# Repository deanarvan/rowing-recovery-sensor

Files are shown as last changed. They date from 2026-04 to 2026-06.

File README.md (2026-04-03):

# Rowing Recovery Sensor

A bilateral force-sensing platform for physical therapy rehabilitation monitoring. Built for tracking lower-extremity recovery metrics — limb symmetry index (LSI), bilateral weight distribution, and force production — during exercises like bilateral stance, heel raises, and squats.

## System Architecture

```
ESP32-S3  →  2× ADS1115 (16-bit ADC)  →  6× FSR-402 sensors  →  BLE  →  Web App
              I2C (GPIO8/9)              (3 per foot: heel,       50 Hz    React/Vite
                                          ball, toe)                       localhost:5174
```

## Repository Structure

```
firmware/           ESP32 Arduino firmware
  rowing_sensor/    Main 6-axis force sensor firmware
  balance_board/    4-load-cell balance board variant
  diagnostics/      I2C scanner and pin finder tools

hardware/           PCB design and build documentation
  kicad/            KiCad schematic, layout, BOM, netlist
  documentation/    Assembly guides, pin reference, design notes

web/                React/Vite web application
  src/components/   UI components (force curves, balance viz, diagnostics)
  src/hooks/        BLE communication, data processing, stroke analysis
  src/utils/        Biomechanics algorithms, session export, calibration

tools/              Python analysis and data logging
  achilles_recovery_analysis.py   Longitudinal PT recovery analysis
  compare_subjects.py             Bilateral comparison report generator
  balance_logger.py               Serial data logger

docs/research/      Biomechanics and rehabilitation reference literature
```

## Quick Start

### Firmware
1. Open `firmware/rowing_sensor/rowing_firmware.ino` in Arduino IDE
2. Select board: ESP32-S3 Dev Module
3. Install library: Adafruit ADS1X15
4. Flash to ESP32-S3

### Web App
```bash
cd web
npm install
npm run dev
# Opens at http://localhost:5174
```

Connect to the sensor via Web Bluetooth (device name: `Rowing_Sensors`).

### Hardware
See `hardware/documentation/START_HERE.txt` for build instructions.

## Key Metrics

| Metric | Description | Clinical Threshold |
|---|---|---|
| LSI | Limb Symmetry Index (injured/uninvolved × 100) | >90% return to sport |
| BSI | Balance Symmetry Index (bilateral weight asymmetry) | <10% general activity |
| Peak Force | BW-normalized peak plantarflexion force | >1.5× BW running readiness |

## Hardware Versions

- **Breadboard prototype**: ESP32-S3 + breadboard + 6× FSR-402 + 2× ADS1115
- **PCB v1**: Custom PCB with same sensor array, improved signal integrity
- **Balance Board**: 4× load cell variant for standing balance assessment

## License

Private — not for redistribution.

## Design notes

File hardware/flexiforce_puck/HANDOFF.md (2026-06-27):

# FlexiForce A301 load-concentrator puck — HANDOFF

**CURRENT:** `make_puck_v3.py` → `flexiforce_puck_4up_v3.stl` (low-profile 4-up, PRINT THIS). Prior: v2 (8 mm×3 mm 4-up), v1 (single).
**Purpose:** rigid disc that routes the balance-board/top-plate load THROUGH it onto the
A301's 9.53 mm active sensing area. Without it the load spreads across the flat sensor and the
A301 under-reads (the ~600-1200 raw-count standing reads in the bring-up). Pure **axial
compression** along the puck axis (+Z); no bending/tension/shear in the intended rig.

## Versions
### v1 (CURRENT) — CadQuery B-rep, chamfered disc
- Params: `PUCK_DIA=8.0`, `PUCK_H=3.0`, `CHAMFER=0.5` (mm). Sensing-area ref `9.53`.
- Build: `circle → extrude → chamfer("%CIRCLE")`. Exports STL + STEP.
- Result (verify all PASS): watertight, single body, euler=2 (plain solid), bbox 8×8×3 mm,
  axisymmetric (COM x,y≈0), top/bottom symmetric (COM z=1.5).
- Numbers: flat contact dia **7.0 mm**; coverage of 9.53 mm area = **84% OD / 73% flat**;
  volume 0.145 cm³; mass **PLA 0.179 g / PETG 0.184 g / PAHT-CF 0.174 g**; 4 pucks ≈ 0.74 g.

### v2 (CURRENT for a set) — 4-up print plate
- `make_puck_v2.py`: same puck, 2×2 grid, `GAP=5` mm → 13 mm pitch, **21×21 mm plate**, 4 SEPARATE bodies.
- Verify all PASS: watertight, **body count 4**, euler **8** (4 disjoint solids), per-body vol = v1 (0.1447 cm³),
  layout symmetric (COM x,y≈0).
- Set mass: **PLA 0.72 g / PETG 0.74 g / PAHT-CF 0.69 g**. A slicer brim across the 5 mm gap holds the four
  during the print, then peels off — no connecting tabs, so nothing to clean off the functional faces.

### v3 (CURRENT) — low-profile, sensor-matched diameter
- `make_puck_v3.py`: **9.5 mm OD × 1.0 mm tall**, 4-up 2×2 @ 14.5 mm pitch → **24×24 mm plate**, CHAMFER 0.3.
- Diameter raised from 8→9.5 to **= the 9.53 mm active area** (full coverage, no overhang). Do NOT exceed 9.53:
  a wider puck overhangs onto the board and load bypasses the sensor (~⅓ reaches the active area at 16 mm) → under-reads.
- Height cut 3→1 mm (low profile, aspect 9.5:1). Symmetric top/bottom (no wrong way up).
- Verify all PASS incl. `OD covers active area` (PUCK_DIA ≤ 9.53) and `4 bodies identical`. Set mass **PETG 0.35 g**.
- **Open design note:** if the user stands *directly* on the pucks (no rigid top-plate), small hard discs are
  uncomfortable and the contact point wanders → poor CoP. Proper construction = rigid top-plate over the 4
  pucks; then the plate handles comfort and the puck stays at the optimal 9.5 mm. A top-plate STL is not yet built.

## HARD INVARIANTS
- `PUCK_DIA < SENSOR_AREA_DIA (9.53)` — puck MUST stay inside the active circle (off-area load = error).
- `PUCK_H` MUST exceed everything else between the sensor and the top plate, or load bypasses the puck.
- euler_number == 2 (plain solid, no holes). Axisymmetric; COM on the z-axis.

## GOTCHAS
- `.edges("%CIRCLE")` chamfers only the two rims, skipping the OCC cylinder seam edge (a LINE).
- Tiny footprint (7 mm flat) → use a **brim** so it doesn't pop off the bed.
- **PLA creeps under sustained bodyweight compression** — use PETG or PAHT-CF for real pucks; PLA only for a fit-check.
- Print **100% infill** (solid) — a load concentrator must not crush; sparse infill would collapse.

## PRINT ORIENTATION (recommended)
**Flat — disc on the bed, axis vertical (layers horizontal, perpendicular to the load).**
- Axial compression loads the layer stack in compression (layers pushed together) = the strong
  direction for FDM; interlayer adhesion (the weak axis) is irrelevant here.
- Both functional faces (top + bottom flats) print flat; no supports; best diameter/height accuracy; fast (3 mm).
- Put the **sensor-contact face UP** and enable **iron top surface** for the flattest contact (marginal — the
  part is nearly symmetric, so either face down is fine; the 0.5 mm chamfer mitigates elephant-foot on the bed face).
- **Flips the call only if** the top plate imparts real SHEAR to the pucks (sliding plate) — then on-edge layers
  would delaminate; stay flat but use PAHT-CF and/or bond the puck down.
- Kit: X2D, PAHT-CF (dried) or PETG, brim, 100% infill, no supports. 0.4 mm nozzle gives crisper chamfers than the
  PAHT-CF 0.6 mm nozzle on a part this small, but 0.6 mm works.

## START BY
Confirm `PUCK_H` matches the real sensor→top-plate gap (the one dimension tied to the assembly), then
`python3 make_puck_v3.py`. Print `flexiforce_puck_4up_v3.stl` (current set of 4). Keep `PUCK_DIA ≤ 9.53`
(active-area rule). Changed a knob? Re-run the script — the verify guard fails loud if the geometry breaks.

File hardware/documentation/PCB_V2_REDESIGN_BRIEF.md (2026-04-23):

# Rowing/Balance Board Rehabilitation Sensor — PCB Design Brief

**Project:** Rowing/Balance Board Rehabilitation Sensor
**Board Size:** 50mm × 70mm, 2-layer
**Manufacturing:** JLCPCB / PCBWay compatible (PCBA assembly service preferred)
**Deliverables:** KiCad schematic (.kicad_sch), PCB layout (.kicad_pcb), Gerbers, BOM with LCSC part numbers, pick-and-place file

---

## Project Overview

This PCB is the central electronics module for a bilateral force-sensing platform used in physical therapy rehabilitation monitoring. It reads four thin-film force sensors (Tekscan FlexiForce A301-100), measures board orientation via a 9-DOF IMU, and streams the combined data to a web application over Bluetooth Low Energy at 50 Hz.

The same hardware supports two operating modes, selected by sensor placement:
- **Rowing mode** — FlexiForce sensors placed in shoe insoles (heel + toe of each foot). The web app detects stroke phases and analyzes force curves.
- **Balance board mode** — FlexiForce sensors placed on a balance platform at heel + toe positions for each foot. The web app computes center of pressure (CoP), sway velocity, ellipse area, and drives interactive balance training games.

Both modes use the same 4 sensor channels and the same BLE data format. The user physically swaps sensor sets by plugging different cables into the 4 front-panel headers.

### Key Design Requirements

| Requirement | Value |
|---|---|
| Force sensor channels | 4 (2 per foot: heel + toe) |
| Force measurement range (per sensor) | 0 to ~2,000 N |
| Sensor type | Tekscan FlexiForce A301-100 thin-film |
| Orientation sensing | 9-DOF IMU (pitch, roll, yaw) |
| Sample rate | 50 Hz per channel |
| Wireless protocol | Bluetooth Low Energy (BLE 5.0) |
| Power input | 5V USB-C |
| Regulated rail | 3.3V (1A capable LDO) |
| Programming | USB serial via CP2102N bridge |
| Board outline | 50mm × 70mm, 2-layer |

---

## System Block Diagram

```
┌─────────────┐
│  USB-C 5V   │
└──────┬──────┘
       │
       ├─ CP2102N USB-to-UART Bridge (U2)
       │  (TX → ESP32 GPIO1, RX ← ESP32 GPIO3)
       │
       ├─ AP2112K-3.3 LDO (U1) ── 3.3V rail
       │
       ├─ ESP32-WROOM-32 (U3)
       │  ├─ I2C SDA = GPIO21, SCL = GPIO22
       │  ├─ GPIO0 (BOOT button)
       │  ├─ EN (RESET button)
       │  └─ BLE antenna (keep-out zone required)
       │
       ├─ MCP6004 Quad Op-Amp (U4) — analog conditioning
       │  ├─ Ch A → FlexiForce: Left Heel  → ADS1115 A0
       │  ├─ Ch B → FlexiForce: Left Toe   → ADS1115 A1
       │  ├─ Ch C → FlexiForce: Right Heel → ADS1115 A2
       │  └─ Ch D → FlexiForce: Right Toe  → ADS1115 A3
       │
       ├─ ADS1115 16-bit I2C ADC @ 0x48 (U5)
       │  ├─ A0-A3 ← Op-amp outputs
       │  ├─ ADDR → GND (sets address 0x48)
       │  └─ Shares I2C bus with IMU
       │
       └─ BNO055 9-DOF IMU @ 0x28 (U6, on-board LGA-28 IC with 32.768 kHz crystal)
          ├─ Outputs: Euler angles, quaternion, linear acceleration
          ├─ ADR → GND (sets address 0x28)
          └─ Shares I2C bus with ADC
```

---

## Analog Front-End Design

### FlexiForce A301 Conditioning Circuit (per channel, ×4)

The FlexiForce A301 is a 2-terminal resistive force sensor. Its resistance decreases as applied force increases. An **inverting op-amp circuit** converts this variable resistance to a proportional output voltage with good linearity across the full force range.

The topology follows the **Tekscan FlexiForce Integration Guide, Figure 4** ("Inverting Amplifier" reference circuit). Per channel:

```
  ┌─────────── Rf (10 kΩ) ──────────┐
  │                                 │
  │        ┌───────────────┐        │
Vref ──────┤(–)             ├───────┴──────┬──── Vout → ADS1115 input (A0–A3)
           │   MCP6004      │              │
    ┌──────┤(+)  (1 of 4)   │              Cf (100 pF, optional)
    │      └───────────────┘               │
   Vref/2 reference                        GND
    │
  (mid-rail bias divider)

  FlexiForce sensor — wired between Vref (drive node) and the (–) input,
  replacing the standard input resistor Rin in the inverting configuration.
```

**Operating principle:** the FlexiForce sits in the position of the inverting-amplifier input resistor. As applied force increases, Rsensor decreases, input current into the summing junction rises, and Vout moves proportionally. The feedback resistor Rf sets the gain (force range). The (+) input is biased to mid-rail (Vref/2) to keep the single-supply op-amp output in the linear region.

Full schematic with exact polarity and biasing: see Tekscan Integration Guide (linked in the Reference Datasheets section). Standard values given below are calibrated for this application.

The op-amp output follows the relation **Vout = Vref × (Rf / Rsensor)**. As force increases, Rsensor decreases, and Vout increases linearly — from ~0V (no force) to ~3V (full range).

### Component Values (per channel)

| Component | Value | Tolerance | Package | Purpose |
|---|---|---|---|---|
| Rf (feedback resistor) | 10 kΩ | 1% | 0603 | Sets force range to ~0–2,000 N |
| Rd (drive resistor) | 10 kΩ | 1% | 0603 | Sets reference current |
| Cf (output filter cap) | 100 pF | 10% | 0603 | Optional low-pass filter |

**Force range tuning** — the Rf value selects the measurement range. 10 kΩ is recommended for this rehabilitation use case:

| Rf | Force Range | Use Case |
|---|---|---|
| 49.9 kΩ | 0 – 445 N | Light touch, seated exercises |
| **10 kΩ** (chosen) | **0 – 2,000 N** | **Standing, squats, heel raises** |
| 4.7 kΩ | 0 – 3,500 N | Heavy dynamic loading |
| 1 kΩ | 0 – 4,448 N | Impact / jump landing |

### Shared Vref Generation

A single voltage divider off the 3.3V rail generates the reference voltage used by all 4 op-amp channels.

```
3.3V ─── Rvd1 (47kΩ) ──┬── Vref (~0.58V) → to Rd on each channel
                         │
                    Rvd2 (10kΩ)
                         │
                        GND
                         │
                    Cvref (100nF to GND)
```

**Vref = 3.3V × 10kΩ / (47kΩ + 10kΩ) ≈ 0.58V**

This low reference voltage keeps the op-amp output within the ADS1115's 0–3.3V input range across the full force range.

### MCP6004 Quad Op-Amp (U4)

The MCP6004 is a quad rail-to-rail input/output op-amp in SOIC-14. A single chip handles all 4 sensor channels.

```
MCP6004 (SOIC-14)
┌──────────────────┐
│ 1  OUT_A    VDD 14│──── 3.3V
│ 2  IN-_A   OUT_D 13│──── → ADS1115 A3 (Right Toe)
│ 3  IN+_A   IN-_D 12│──── Rf_D + Rd_D
│ 4  VSS     IN+_D 11│──── GND (sensor reference)
│ 5  IN+_B   IN-_C 10│──── Rf_C + Rd_C
│ 6  IN-_B   IN+_C  9│──── GND (sensor reference)
│ 7  OUT_B   OUT_C   8│──── → ADS1115 A2 (Right Heel)
└──────────────────┘
```

Channel assignments:

| MCP6004 Channel | OUT / IN– / IN+ pins | Sensor | ADS1115 Input |
|---|---|---|---|
| A | 1 / 2 / 3 | Left Heel | A0 |
| B | 7 / 6 / 5 | Left Toe | A1 |
| C | 8 / 10 / 9 | Right Heel | A2 |
| D | 13 / 12 / 14 | Right Toe | A3 |

**Power:** VDD (pin 14) to 3.3V with 100nF + 10µF decoupling placed within 5mm of the pin. VSS (pin 4) to ground plane.

---

## Digital Section

### ADS1115 16-bit ADC (U5)

Single ADS1115 reads all 4 op-amp outputs over I2C.

| Pin | Name | Connection |
|---|---|---|
| 1 | VDD | 3.3V (with 100nF decoupling cap to GND) |
| 2 | A0 | MCP6004 Channel A output (Left Heel) |
| 3 | A1 | MCP6004 Channel B output (Left Toe) |
| 4 | A2 | MCP6004 Channel C output (Right Heel) |
| 5 | A3 | MCP6004 Channel D output (Right Toe) |
| 6 | GND | Ground plane |
| 7 | SDA | I2C SDA bus (GPIO21) |
| 8 | SCL | I2C SCL bus (GPIO22) |
| 9 | ADDR | GND (sets I2C address to 0x48) |
| 10 | ALERT | Leave unconnected |

### BNO055 9-DOF IMU (U6)

The BNO055 provides absolute orientation with onboard sensor fusion (Euler angles, quaternion, linear acceleration, gravity vector) — no host-side filtering required. The IC is placed **directly on the PCB** alongside its supporting crystal and decoupling components. JLCPCB's PCBA service handles the LGA-28 placement; no post-assembly work is required.

#### BNO055 IC Pinout (LGA-28)

| Pin | Name | Connection |
|---|---|---|
| 1 | VDDIO | 3.3V (with 100nF decoupling cap to GND) |
| 3 | GND | Ground plane |
| 4 | XIN32 | Crystal pin 1 (with 22pF load cap to GND) |
| 5 | XOUT32 | Crystal pin 2 (with 22pF load cap to GND) |
| 6 | BL_IND | 10 kΩ pull-up to 3.3V |
| 8 | PS1 | GND (standard I²C mode) |
| 9 | PS0 | GND (standard I²C mode) |
| 17 | COM3 (ADR) | GND (sets I²C address to 0x28) |
| 18 | COM2 (INT) | ESP32 GPIO4 (optional motion interrupt; leave floating if unused) |
| 19 | COM1 (SCL) | I²C SCL bus (GPIO22) |
| 20 | COM0 (SDA) | I²C SDA bus (GPIO21) |
| 23 | nRESET | Pull up to 3.3V via 10 kΩ; optional tie to ESP32 GPIO5 for hardware reset |
| 28 | VDD | 3.3V (with 100nF decoupling cap to GND) |

(All other pins: leave unconnected or tied to GND per datasheet recommendations.)

#### Supporting Components

| Ref | Value | Purpose |
|---|---|---|
| Y1 | 32.768 kHz quartz crystal, 12.5 pF load | External timing reference — required for accurate sensor fusion |
| Cxtal1, Cxtal2 | 22 pF NP0 | Crystal load capacitors (tie to GND, placed within 3mm of crystal) |
| Cbno_io | 100 nF | VDDIO decoupling (placed within 2mm of pin 1) |
| Cbno_d | 100 nF | VDD decoupling (placed within 2mm of pin 28) |
| Rbl | 10 kΩ | BL_IND pull-up to 3.3V |
| Rrst | 10 kΩ | nRESET pull-up to 3.3V |

Crystal routing: keep traces short and symmetric, surround with ground pour, do not route high-speed signals underneath.

### I2C Bus

Both devices share one I2C bus driven by the ESP32 on GPIO21 (SDA) and GPIO22 (SCL).

| Device | Address | Package |
|---|---|---|
| ADS1115 | 0x48 | MSOP-10 on-board |
| BNO055 | 0x28 | LGA-28 on-board |

Bus pull-ups: 4.7 kΩ to 3.3V on both SDA and SCL. 400 kHz fast mode.

### IMU Axis Alignment

Orient the BNO055 IC on the PCB so that its internal axes align with the board's physical frame of reference:

- **IMU X+** → board length direction (anterior, toward the toe-end of the sensor layout)
- **IMU Y+** → board width direction (medial-lateral)
- **IMU Z+** → up (perpendicular to PCB surface)

With this alignment, pitch rotates around Y, roll rotates around X, yaw rotates around Z. Document the chosen orientation on the silkscreen with a small arrow so the operator can verify placement.

### ESP32-WROOM-32 (U3)

Standard ESP32-WROOM-32 module handles all logic and BLE wireless.

| Pin | Name | Connection |
|---|---|---|
| 1 | GND | Ground plane |
| 2 | VCC | 3.3V rail |
| 3 | RXD (GPIO3) | UART RX from CP2102N |
| 4 | EN | RESET button + 10 kΩ pull-up to 3.3V |
| 27 | GPIO0 | BOOT button + 10 kΩ pull-up to 3.3V |
| 21 | GPIO21 | I2C SDA (4.7 kΩ pull-up) |
| 22 | GPIO22 | I2C SCL (4.7 kΩ pull-up) |

**Antenna keep-out:** no copper (traces or ground plane) within 10mm of the ESP32 antenna end. The antenna should overhang the board edge or sit in a dedicated clear zone.

### CP2102N USB-to-UART Bridge (U2)

Standard USB programming interface.

| Pin | Name | Connection |
|---|---|---|
| 1 | VCC | 3.3V (with 100nF decoupling) |
| 3 | D+ | USB connector D+ (via 22Ω series resistor) |
| 4 | D- | USB connector D- (via 22Ω series resistor) |
| 5 | TXD | ESP32 GPIO1 (via 1 kΩ series resistor) |
| 6 | RXD | ESP32 GPIO3 (via 1 kΩ series resistor) |
| 10 | REGIN | 5V rail (with 100nF decoupling) |

### Power Supply

| Net | Voltage | Source | Notes |
|---|---|---|---|
| 5V_USB | 5.0V | USB-C connector | Max 500 mA per USB spec |
| 3V3 | 3.3V | AP2112K-3.3 LDO | 600 mA capacity; 55 µA quiescent; typical draw <200 mA |
| GND | 0V | Continuous ground plane | |

Decoupling: 100nF + 10µF on LDO input and output. 100nF per IC VDD pin placed within 5mm.

---

## Sensor Connectors

**4× 2-pin 2.54mm female through-hole headers (J2–J5)**

The FlexiForce A301 terminates in 2 male square pins at 0.1" pitch. These plug directly into standard 2-pin female headers on the PCB — no adapter cables, no soldering to the sensor, easy swap for replacement.

| Connector | Sensor | Op-Amp Channel | ADS1115 Input |
|---|---|---|---|
| J2 | Left Heel FlexiForce | MCP6004 Ch A | A0 |
| J3 | Left Toe FlexiForce | MCP6004 Ch B | A1 |
| J4 | Right Heel FlexiForce | MCP6004 Ch C | A2 |
| J5 | Right Toe FlexiForce | MCP6004 Ch D | A3 |

**Each connector:**
- Pin 1: Sensor signal → 100 Ω series resistor → TVS clamp → MCP6004 IN+ (non-inverting input)
- Pin 2: GND

**Part:** 2-pin 2.54mm female header, through-hole (LCSC C35165 or equivalent). Place J2–J5 along one board edge for clean cable routing.

### ESD Protection (per sensor input)

Since FlexiForce sensors will be plugged and unplugged repeatedly during clinical use, each sensor input gets basic ESD/transient protection between the connector and the op-amp input:

| Component | Value | Purpose | Placement |
|---|---|---|---|
| Resd (×4) | 100 Ω | Series current-limit resistor on signal pin | Between J2–J5 pin 1 and TVS clamp |
| D_esd (×4) | PESD3V3L1BA | Unidirectional TVS diode, 3.3V working voltage, SOD-523 package | Between signal (after Resd) and GND, cathode to signal |

This adds negligible noise (100 Ω against the op-amp's MΩ-range input impedance is invisible) but clamps any static discharge or cable swap transient before it reaches the op-amp.

---

## Bill of Materials

All components mount directly on the PCB. The only off-board items are the FlexiForce sensors themselves, which plug into the four front-edge headers.

| Designator | Value / Part | Description | Package | LCSC | Qty |
|---|---|---|---|---|---|
| U1 | AP2112K-3.3TRG1 | 3.3V LDO regulator, 55 µA Iq, low dropout | SOT-25 | C51118 | 1 |
| U2 | CP2102N | USB-to-UART bridge | QFN-28 | C7520 | 1 |
| U3 | ESP32-WROOM-32 | BLE/WiFi MCU module | 38-pin module | C529143 | 1 |
| U4 | MCP6004-I/ST | Quad rail-to-rail op-amp | SOIC-14 | C7378 | 1 |
| U5 | ADS1115 | 16-bit I²C ADC | MSOP-10 | C21992 | 1 |
| U6 | BNO055 | 9-DOF absolute orientation sensor with onboard fusion | LGA-28 (5.2×3.8mm) | C40521 | 1 |
| Y1 | 32.768 kHz crystal, 12.5 pF load | BNO055 external timing crystal | SMD 3.2×1.5mm | C32346 | 1 |
| Cxtal1 | 22 pF NP0 | Crystal load cap | 0402 | C1554 | 1 |
| Cxtal2 | 22 pF NP0 | Crystal load cap | 0402 | C1554 | 1 |
| Cbno_io | 100 nF | BNO055 VDDIO decoupling | 0402 | C1525 | 1 |
| Cbno_d | 100 nF | BNO055 VDD decoupling | 0402 | C1525 | 1 |
| Rbl | 10 kΩ | BNO055 BL_IND pull-up | 0402 | C25744 | 1 |
| Rrst | 10 kΩ | BNO055 nRESET pull-up | 0402 | C25744 | 1 |
| Rf1–Rf4 | 10 kΩ 1% | Op-amp feedback resistors | 0603 | C25804 | 4 |
| Rd1–Rd4 | 10 kΩ 1% | Op-amp drive resistors | 0603 | C25804 | 4 |
| Rvd1 | 47 kΩ 1% | Vref divider (top) | 0603 | C25819 | 1 |
| Rvd2 | 10 kΩ 1% | Vref divider (bottom) | 0603 | C25804 | 1 |
| R10 | 4.7 kΩ | I²C SDA pull-up | 0603 | C14631 | 1 |
| R11 | 4.7 kΩ | I²C SCL pull-up | 0603 | C14631 | 1 |
| R12 | 10 kΩ | GPIO0 (BOOT) pull-up | 0603 | C14663 | 1 |
| R13 | 10 kΩ | EN (RESET) pull-up | 0603 | C14663 | 1 |
| R14 | 22 Ω | USB D+ series resistor | 0603 | C25119 | 1 |
| R15 | 22 Ω | USB D- series resistor | 0603 | C25119 | 1 |
| R_LED | 1 kΩ | Power LED current limit | 0603 | C14663 | 1 |
| R_UART1 | 1 kΩ | CP2102 TX series | 0603 | C14663 | 1 |
| R_UART2 | 1 kΩ | CP2102 RX series | 0603 | C14663 | 1 |
| Cvref | 100 nF | Vref bypass cap | 0603 | C14663 | 1 |
| Cpa | 100 nF | MCP6004 VDD decoupling | 0603 | C14663 | 1 |
| Cpb | 10 µF | MCP6004 VDD bulk cap | 1206 | C13585 | 1 |
| Ca5 | 100 nF | ADS1115 VDD decoupling | 0603 | C14663 | 1 |
| C1 | 100 nF | CP2102N VCC decoupling | 0603 | C14663 | 1 |
| C2 | 10 µF | Input bulk cap (5V) | 1206 | C13585 | 1 |
| C3 | 100 nF | LDO output decoupling | 0603 | C14663 | 1 |
| C4 | 10 µF | LDO output bulk cap | 1206 | C13585 | 1 |
| C5 | 100 nF | ESP32 VCC decoupling | 0603 | C14663 | 1 |
| C10 | 100 nF | BOOT debounce (optional) | 0603 | C14663 | 1 |
| C11 | 100 nF | RESET debounce (optional) | 0603 | C14663 | 1 |
| LED1 | Red LED | Power indicator | 0603 | C2286 | 1 |
| SW1 | 6×6mm tactile button | BOOT | SMD 6×6mm | C318884 | 1 |
| SW2 | 6×6mm tactile button | RESET | SMD 6×6mm | C318884 | 1 |
| J1 | USB-C receptacle, 24-pin | USB connector (mid-mount) | USB-C SMD | C165948 | 1 |
| J2–J5 | 2-pin female header, 2.54mm | Sensor connectors | TH 2.54mm | C35165 | 4 |
| Resd1–Resd4 | 100 Ω | Sensor input series resistor (ESD current limit) | 0402 | C25092 | 4 |
| Desd1–Desd4 | PESD3V3L1BA | Unidirectional TVS diode, 3.3V clamping | SOD-523 | C129319 | 4 |

Estimated per-board cost: ~$15 in components plus ~$2–5 PCB fabrication (JLCPCB 5-piece minimum).

### Off-Board Parts (Not on PCB)

| Part | Source | Purpose |
|---|---|---|
| Tekscan FlexiForce A301-100 (×4 or ×6 with spares) | DigiKey / Tekscan | Force sensors; plug into J2–J5 |

The IMU is integrated directly on the PCB — no separate module to purchase.

---

## PCB Layout Guidelines

### Analog Signal Routing (Critical)

1. **Keep MCP6004 output traces short** — route directly to ADS1115 inputs with minimal trace length (<10mm ideal).
2. **Star ground** — connect MCP6004 VSS, ADS1115 GND, and the Vref divider bottom to a single node on the ground plane near the analog section.
3. **Separate analog and digital zones** — ESP32 and CP2102N on one side of the board, MCP6004/ADS1115/BNO055 on the other. Join the two zones at a single point under the LDO.
4. **Vref trace** — route the Vref net from the divider to all 4 Rd resistors on the top layer, keep away from digital switching traces.
5. **Sensor connector placement** — J2–J5 along one edge for easy cable routing.

### Suggested Component Placement

```
50mm × 70mm Board (Top View)
┌────────────────────────────────────────┐
│  [USB-C]  [CP2102N]  [LED] [SW1][SW2] │  ← Digital section (top edge)
│                                        │
│         [ESP32-WROOM-32]               │  ← Center; keep antenna clear
│         (large module)                 │
│                                        │
│  [MCP6004]  [ADS1115]    [BNO055]     │  ← Analog + IMU section
│  [Rf1-4]    [Rd1-4]      [Y1 xtal]    │     IMU IC directly on board
│  [Rvd1/2]   [Cvref]                   │
│                                        │
│  [J2]  [J3]  [J4]  [J5]              │  ← Sensor connectors (bottom edge)
└────────────────────────────────────────┘
```

### Trace / Via Specifications

- Signal traces: 0.25mm minimum width
- Power traces: 0.5mm minimum width
- Via diameter: 0.3mm minimum drill, 0.6mm pad
- Ground plane: continuous on bottom layer
- 2-layer, 1oz copper

### ESP32 Antenna Keep-Out

No copper (traces or ground plane) within 10mm of the ESP32 antenna end. The module should be oriented so the antenna overhangs the board edge or has a dedicated clear zone.

### IMU Placement

Place the BNO055 IC (U6) and its 32.768 kHz crystal (Y1) together in a small quiet zone, away from the ESP32 module and high-speed digital traces. Surround the crystal with a local ground pour. Add a silkscreen arrow next to U6 indicating the chosen X-axis direction so firmware and the web app can interpret axes correctly. The 22 pF load caps (Cxtal1, Cxtal2) must be within 3 mm of the crystal pins.

---

## Calibration Procedure (Post-Assembly)

Run once per assembled board to establish per-channel force calibration:

1. Power the board with no load on any sensor — record the zero-offset ADC reading per channel.
2. Place a known weight (e.g., 20 kg plate) centered on each FlexiForce sensor — record the loaded ADC reading.
3. Compute per-channel scale factor: `scale = known_force_N / (loaded_reading − zero_reading)`.
4. Store scale factors in ESP32 non-volatile storage (NVS) or hardcode in firmware.

**Expected with Rf = 10 kΩ:** approximately 16 ADC counts per Newton, so the full 0–2000 N range maps to 0–32,000 counts (well within the ADS1115's 16-bit resolution).

---

## Testing Checklist

### Power-On
- [ ] LED1 illuminates
- [ ] 3.3V rail measures 3.28–3.35 V
- [ ] Current draw <100 mA with no BLE connection

### Vref Verification
- [ ] Measure Vref node: 0.55–0.60 V

### Op-Amp Verification (sensors disconnected)
- [ ] MCP6004 pin 14 (VDD): 3.3 V
- [ ] MCP6004 pin 4 (VSS): 0 V
- [ ] Op-amp outputs (pins 1, 7, 8, 13): ~0 V with no sensor current

### I²C / ADC Verification
- [ ] I²C scanner finds 0x48 (ADS1115) AND 0x28 (BNO055)
- [ ] All 4 ADC channels read near 0 with sensors disconnected
- [ ] Channels respond smoothly when a test voltage is applied

### IMU Verification
- [ ] I²C scanner finds BNO055 at address 0x28
- [ ] Crystal oscillates (firmware reports successful IMU init)
- [ ] Board flat on bench: pitch ≈ 0°, roll ≈ 0°
- [ ] Tilt board 45° forward: pitch reads ~45°
- [ ] Tilt board 45° sideways: roll reads ~45°
- [ ] Rotate board: yaw changes smoothly (absolute heading)
- [ ] No cross-coupling (pitch changes don't affect roll, etc.)

### Sensor Verification (with FlexiForce connected)
- [ ] Light finger press: small ADC reading (~100–500 counts)
- [ ] Full hand press: larger reading (~5,000–15,000 counts)
- [ ] Full standing bodyweight: ~13,000 counts for ~800 N — no saturation

### BLE Verification
- [ ] Device advertises as "Rowing_Sensors"
- [ ] Web app connects and displays live data for all 4 force channels and IMU
- [ ] 50 Hz data rate confirmed

### Clinical Verification
- [ ] Bilateral stance: Left % ≈ Right % (±5%)
- [ ] Single-leg stance: loaded side reads ~800 N (1× bodyweight)
- [ ] Heel raise: peak >1,200 N (>1.5× bodyweight) — no saturation
- [ ] Squat: peak >1,500 N (>1.8× bodyweight) — no saturation

---

## Reference Datasheets

| Component | Datasheet |
|---|---|
| FlexiForce A301 | https://www.tekscan.com/products-solutions/force-sensors/flexiforce-a301-sensor |
| FlexiForce Integration Guide | https://www.tekscan.com/resources/user-manual/flexiforce-sensors-integration-guide |
| MCP6004 | https://ww1.microchip.com/downloads/en/DeviceDoc/MCP6001-1R-1U-2-4-1MHz-Low-Power-Op-Amp-DS20001733L.pdf |
| ADS1115 | https://www.ti.com/lit/ds/symlink/ads1115.pdf |
| BNO055 | https://cdn-shop.adafruit.com/datasheets/BST_BNO055_DS000_12.pdf |
| Adafruit BNO055 reference design (for layout hints) | https://www.adafruit.com/product/2472 |
| ESP32-WROOM-32 | https://www.espressif.com/sites/default/files/documentation/esp32-wroom-32_datasheet_en.pdf |
| CP2102N | https://www.silabs.com/documents/public/data-sheets/cp2102n-a01-datasheet.pdf |
| AP2112K-3.3 | https://www.diodes.com/assets/Datasheets/AP2112.pdf |
| PESD3V3L1BA (TVS) | https://www.nexperia.com/products/esd-protection-and-emi-filtering/esd-protection-diodes/PESD3V3L1BA.html |

---

## Dual-Mode Operation Note

The same PCB supports both rowing and balance-board modes. The sensors themselves are swapped physically (different cable harnesses plugged into J2–J5). No firmware mode switching is required — the ESP32 always reports the same 4 force channels plus IMU data, and the web application interprets the data based on which tab the user has selected.

| Operating Mode | Sensor Placement | Web App View |
|---|---|---|
| Rowing | FlexiForce sensors inside shoe insoles (heel + toe per foot) | "Rowing" — stroke phase, force curves |
| Balance Board | FlexiForce sensors on balance-board surface (heel + toe zones per foot) | "Balance Board" — CoP, sway, training games |

The IMU remains active in both modes. In rowing mode, orientation data provides context for drive/recovery timing. In balance mode, it measures board tilt (if mounted on a wobble/rocker platform) or, when the PCB is extended to a chest strap via cable, trunk sway during postural assessment.

---

## Deliverables Expected

1. Schematic (.kicad_sch) with clearly labeled nets
2. PCB layout (.kicad_pcb) respecting the layout guidelines above
3. Manufacturing Gerbers (zip)
4. BOM in CSV format with LCSC part numbers matching the table above
5. Pick-and-place file for PCBA
6. 3D render / preview image of the assembled board
7. DRC and ERC reports (clean)

---

**Document Version:** 1.0 (April 2026)
**Prepared by:** Dean Arvan
**Contact:** deanarvan@gmail.com

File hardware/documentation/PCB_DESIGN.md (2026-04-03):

# Rowing/Balance Board Rehabilitation Sensor PCB Design Document

**Project:** Rowing Balance Board Rehabilitation Sensor
**Date:** March 2026
**Target Board Size:** 50mm × 70mm (approximately credit card size)
**Manufacturing:** JLCPCB / PCBWay compatible

---

## Table of Contents

1. [System Overview](#system-overview)
2. [Design Specifications](#design-specifications)
3. [Schematic Design](#schematic-design)
4. [Component-by-Component Wiring Guide](#component-by-component-wiring-guide)
5. [Bill of Materials (BOM)](#bill-of-materials-bom)
6. [PCB Layout Recommendations](#pcb-layout-recommendations)
7. [Manufacturing Notes](#manufacturing-notes)
8. [Assembly Instructions](#assembly-instructions)
9. [Testing Checklist](#testing-checklist)

---

## System Overview

This PCB consolidates a working breadboard prototype of a rehabilitation sensor system that monitors pressure distribution across a rowing/balance board using six Force Sensing Resistors (FSRs). The system uses Bluetooth Low Energy (BLE) to transmit sensor data at 50 Hz sampling rate.

### Key Features

- **Microcontroller:** ESP32-WROOM-32 (raw module, not dev board)
- **Analog Input:** 2× ADS1115 16-bit ADCs for 6 FSR sensors
- **Wireless:** BLE via ESP32
- **Programming:** USB-C with integrated CP2102N USB-to-UART bridge
- **Power:** 5V USB input → 3.3V LDO regulator
- **Future:** Battery connector for standalone operation
- **Sampling Rate:** 50 Hz per channel

### Block Diagram

```
┌─────────────┐
│  USB-C 5V   │
└──────┬──────┘
       │
       ├─ CP2102N UART Bridge
       │  (TX → ESP32 GPIO1, RX ← ESP32 GPIO3)
       │
       ├─ 3.3V LDO (AMS1117)
       │
       ├─ ESP32-WROOM-32
       │  ├─ I2C (SDA=GPIO21, SCL=GPIO22)
       │  ├─ GPIO0 (BOOT button for programming)
       │  ├─ EN (Reset button)
       │  └─ GND
       │
       ├─ ADS1115 @ 0x48 (Left Foot)
       │  ├─ A0 → Left Heel FSR
       │  ├─ A1 → Left Ball FSR
       │  ├─ A2 → Left Toe FSR
       │  └─ I2C bus
       │
       └─ ADS1115 @ 0x49 (Right Foot)
          ├─ A0 → Right Heel FSR
          ├─ A1 → Right Ball FSR
          ├─ A2 → Right Toe FSR
          └─ I2C bus
```

---

## Design Specifications

### Electrical Specifications

| Parameter | Value | Notes |
|---|---|---|
| Input Voltage | 5V USB | Via USB-C connector |
| Regulated Voltage | 3.3V | AMS1117-3.3 LDO, 1A capability |
| I2C Bus Voltage | 3.3V | Pull-up to 3.3V |
| I2C Clock Speed | 400 kHz | Standard fast mode |
| ADC Resolution | 16-bit | ADS1115 |
| ADC Sampling Rate | 50 Hz | Per channel |
| Maximum Current (3.3V) | ~500mA | ESP32 + ADS chips + peripherals |

### Physical Specifications

| Parameter | Value |
|---|---|
| PCB Size | 50mm × 70mm |
| Layer Count | 2 layers |
| Via Size | 0.3mm diameter (standard) |
| Trace Width | ≥0.25mm (signal), ≥0.5mm (power) |
| Copper Finish | HASL or Lead-free HASL |
| Soldermask | Green or red (any color) |
| Silkscreen | White |

### Temperature & Environment

- Operating Temperature: 0°C to 50°C
- Storage Temperature: -20°C to 85°C
- Humidity: Non-condensing
- Coating: Optional conformal coating for durability

---

## Schematic Design

### Netlist Format (Detailed Connections)

#### Power Distribution Network

```
Power Rails:
- 5V_USB (from USB-C VCC)
- 3V3 (from AMS1117 LDO output)
- GND (all grounds tied together)

Decoupling Capacitors:
- C1: 100nF (0603) from 5V_USB to GND (near USB connector)
- C2: 10µF (1206) from 5V_USB to GND (bulk, near USB connector)
- C3: 100nF (0603) from 3V3 to GND (near LDO output, close to LDO pin)
- C4: 100nF (0603) from 3V3 to GND (near ESP32)
- C5: 100nF (0603) from 3V3 to GND (near ADS1115 #1)
- C6: 100nF (0603) from 3V3 to GND (near ADS1115 #2)
- C7: 10µF (1206) bulk capacitor, 3V3 to GND
```

#### USB Power Input & UART Bridge

```
USB-C Connector (USB_CONN):
- Pin 1: GND → GND plane
- Pin 2: CC1 (not used)
- Pin 3: D- → CP2102N D-
- Pin 4: SBU1 (not used)
- Pin 5: VBUS → 5V_USB (with 100nF+10µF caps nearby)
- Pin 6: SBU2 (not used)
- Pin 7: D+ → CP2102N D+
- Pin 8: CC2 (not used)
- Pin 9: GND → GND plane

CP2102N USB-to-UART Bridge (U2):
- VCC (pin 1) → 3.3V (via 100nF capacitor)
- GND (pin 2) → GND plane
- D+ (pin 3) → USB-C D+ (via 22Ω series resistor)
- D- (pin 4) → USB-C D- (via 22Ω series resistor)
- TXD (pin 5) → ESP32 GPIO3 (RXD input)
- RXD (pin 6) → ESP32 GPIO1 (TXD output)
- RST (pin 7) → 3.3V (via 100nF to GND, with manual reset to GND for programming)
- CTS (pin 8) → 3.3V (via pull-up resistor)
- RTS (pin 9) → GND or no-connect
- REGIN (pin 10) → 5V_USB (with series 100nF cap)
- Integrated pull-up resistors on D+/D- (no additional pull-ups needed)
```

#### Voltage Regulation

```
AMS1117-3.3 LDO Regulator (U1):
- IN (pin 3) → 5V_USB (with upstream filtering caps)
- OUT (pin 2) → 3V3 rail (to all 3.3V consumers)
- GND (pin 1) → GND plane
- Capacitors:
  - 10µF (1206) from IN to GND (input bulk cap)
  - 100nF (0603) from IN to GND (input filter)
  - 10µF (1206) from OUT to GND (output bulk cap)
  - 100nF (0603) from OUT to GND (output filter, very close to pin)
```

#### ESP32-WROOM-32 Module (U3)

```
Pin Assignments (standard ESP32 module pinout):

Power:
- VCC (pins 1, 2) → 3V3 rail (with 100nF cap to GND)
- GND (pins 15, 16, 17, 18, 19, 34) → GND plane

I2C Bus:
- GPIO21 (SDA) → I2C_SDA (with 4.7kΩ pull-up to 3.3V)
- GPIO22 (SCL) → I2C_SCL (with 4.7kΩ pull-up to 3.3V)

UART (for programming via CP2102N):
- GPIO1 (TXD) → CP2102N RXD via 1kΩ series resistor
- GPIO3 (RXD) → CP2102N TXD via 1kΩ series resistor

Programming Control:
- GPIO0 (BOOT) → BOOT button to GND, with 10kΩ pull-up to 3.3V
- EN (Reset) → RESET button to GND, with 10kΩ pull-up to 3.3V

Unused Pins:
- All other GPIO pins left unconnected or tied via 100kΩ pull-up/down as needed
- TX/RX should not be used simultaneously with GPIO1/GPIO3
```

#### I2C Pull-Up Resistors

```
I2C_SDA Line:
- 4.7kΩ resistor from SDA to 3V3 (R9)
- Connected to: ESP32 GPIO21 + ADS1115 #1 SDA + ADS1115 #2 SDA

I2C_SCL Line:
- 4.7kΩ resistor from SCL to 3V3 (R10)
- Connected to: ESP32 GPIO22 + ADS1115 #1 SCL + ADS1115 #2 SCL
```

#### ADS1115 ADC #1 (Left Foot) @ I2C Address 0x48 (U4)

```
Pin Assignments (MSOP-10 package):

Power:
- VDD (pin 1) → 3V3 rail
- GND (pin 5) → GND plane
- DECAP (pin 10) → 100nF cap to GND

I2C Bus:
- SDA (pin 6) → I2C_SDA (shared with ESP32 and ADS1115 #2)
- SCL (pin 7) → I2C_SCL (shared with ESP32 and ADS1115 #2)

Address Configuration:
- ADDR (pin 8) → GND (sets I2C address to 0x48)

Analog Inputs (0-3V3 range):
- A0 (pin 2) → Left Heel FSR voltage divider output (via connector J2)
- A1 (pin 3) → Left Ball FSR voltage divider output (via connector J3)
- A2 (pin 4) → Left Toe FSR voltage divider output (via connector J4)
- A3 (pin 9) → GND (unused, tie to GND)

Reference Voltage:
- REFIN (pin 9) → GND (internal reference used)
```

#### ADS1115 ADC #2 (Right Foot) @ I2C Address 0x49 (U5)

```
Pin Assignments (MSOP-10 package):

Power:
- VDD (pin 1) → 3V3 rail
- GND (pin 5) → GND plane
- DECAP (pin 10) → 100nF cap to GND

I2C Bus:
- SDA (pin 6) → I2C_SDA (shared with ESP32 and ADS1115 #1)
- SCL (pin 7) → I2C_SCL (shared with ESP32 and ADS1115 #1)

Address Configuration:
- ADDR (pin 8) → 3V3 (sets I2C address to 0x49)

Analog Inputs (0-3V3 range):
- A0 (pin 2) → Right Heel FSR voltage divider output (via connector J5)
- A1 (pin 3) → Right Ball FSR voltage divider output (via connector J6)
- A2 (pin 4) → Right Toe FSR voltage divider output (via connector J7)
- A3 (pin 9) → GND (unused, tie to GND)

Reference Voltage:
- REFIN (pin 9) → GND (internal reference used)
```

#### Voltage Dividers for FSR Sensors

```
For each of 6 FSR inputs (Left Heel, Left Ball, Left Toe, Right Heel, Right Ball, Right Toe):

Voltage Divider Circuit:
- 3V3 → 10kΩ reference resistor (R_ref) → ADC input → FSR → GND

Component Details:
- Reference resistor: 10kΩ (0603 or 0805) at each divider
- FSR sensors: Externally connected via JST-PH 2-pin connectors
- One FSR pin → GND, other FSR pin → ADC input (between reference resistor and FSR)
- Capacitor (optional, for noise filtering): 100nF from ADC input to GND

Voltage Divider Schematic (per channel):
         3V3
          │
        R_ref (10kΩ)
          │
  ─────────┬────── ADC_input (to ADS1115 channel)
           │
         FSR (from JST connector)
           │
          GND

Resistor Assignments:
- R1: Left Heel voltage divider (10kΩ, 0603)
- R2: Left Ball voltage divider (10kΩ, 0603)
- R3: Left Toe voltage divider (10kΩ, 0603)
- R4: Right Heel voltage divider (10kΩ, 0603)
- R5: Right Ball voltage divider (10kΩ, 0603)
- R6: Right Toe voltage divider (10kΩ, 0603)
```

#### FSR Sensor Connectors (JST-PH 2-pin)

```
J2: Left Heel FSR
- Pin 1 → GND
- Pin 2 → ADS1115 #1 A0 (via R1 voltage divider)

J3: Left Ball FSR
- Pin 1 → GND
- Pin 2 → ADS1115 #1 A1 (via R2 voltage divider)

J4: Left Toe FSR
- Pin 1 → GND
- Pin 2 → ADS1115 #1 A2 (via R3 voltage divider)

J5: Right Heel FSR
- Pin 1 → GND
- Pin 2 → ADS1115 #2 A0 (via R4 voltage divider)

J6: Right Ball FSR
- Pin 1 → GND
- Pin 2 → ADS1115 #2 A1 (via R5 voltage divider)

J7: Right Toe FSR
- Pin 1 → GND
- Pin 2 → ADS1115 #2 A2 (via R6 voltage divider)
```

#### Power Indicator LED

```
Power LED (LED1):
- Configuration: Red LED with 1kΩ current-limiting resistor
- Anode (+) → 3V3 via 1kΩ resistor (R11)
- Cathode (-) → GND
- Purpose: Visual indicator that 3.3V rail is powered
- Current: ~3mA at 3V3 with 1kΩ resistor
```

#### Programming Buttons

```
BOOT Button (SW1):
- Function: Puts ESP32 into bootloader mode for UART programming
- Connection: GPIO0 to GND
- Pull-up: 10kΩ resistor from GPIO0 to 3V3
- Sequence: Hold BOOT, then press RESET, release RESET, release BOOT
- Footprint: 6×6mm SMD tactile switch (standard)

RESET Button (SW2):
- Function: Resets the ESP32 and restarts the application
- Connection: EN pin to GND
- Pull-up: 10kΩ resistor from EN to 3V3
- Hold time: Brief press for normal reset
- Footprint: 6×6mm SMD tactile switch (standard)
```

#### Battery Connector (Optional Future Use)

```
Battery Connector (J8) - JST-PH 2-pin:
- Pin 1: GND (black wire convention)
- Pin 2: VBAT (red wire convention, max 4.2V for LiPo)
- NOT POPULATED in initial design
- When populated: Add diode and charging circuit (future iteration)
- Current design uses USB power only
```

#### Test Points (Optional but Recommended)

```
TP1: 5V_USB (for power verification)
TP2: 3V3 (for power verification)
TP3: GND (reference)
TP4: I2C_SDA (for debugging)
TP5: I2C_SCL (for debugging)
```

---

## Component-by-Component Wiring Guide

### U1: AMS1117-3.3 Voltage Regulator

**Part:** AMS1117-3.3 SOT-223 package

| Pin | Name | Connection | Notes |
|-----|---|---|---|
| 1 | GND | Ground plane | Thermal pad should be soldered |
| 2 | VOUT | 3V3 rail | Via 100nF + 10µF output caps |
| 3 | VIN | 5V_USB input | Via 100nF + 10µF input caps |
| 4 | ADJ | Not used | Leave floating for fixed 3.3V output |

**Capacitor Requirements:**
- Input: 100nF (0603) + 10µF (1206) in parallel
- Output: 100nF (0603) + 10µF (1206) in parallel
- Place output 100nF cap as close as possible to pin 2

### U2: CP2102N USB-to-UART Bridge

**Part:** CP2102N QFN-28 package

| Pin | Name | Connection | Purpose |
|-----|---|---|---|
| 1 | VCC | 3V3 via 100nF cap | IC power supply |
| 2 | GND | Ground plane | IC ground |
| 3 | D+ | USB connector pin 7 via 22Ω | USB D+ signal line |
| 4 | D- | USB connector pin 3 via 22Ω | USB D- signal line |
| 5 | TXD | ESP32 GPIO3 via 1kΩ | UART TX to ESP32 RX |
| 6 | RXD | ESP32 GPIO1 via 1kΩ | UART RX from ESP32 TX |
| 7 | RST | 3V3 via 100nF to GND | Reset control (high = normal op) |
| 8 | CTS | 3V3 pull-up via 10kΩ | Clear-to-Send (can tie to VCC) |
| 9 | RTS | GND or no-connect | Request-to-Send |
| 10 | REGIN | 5V_USB via 100nF to GND | Integrated regulator input |
| Remaining pins | Substrate/Thermal | GND plane | Ground connection |

**Key Notes:**
- CP2102N includes integrated voltage regulator, no external reg needed for this chip
- USB pull-up resistors are integrated (do not add external)
- Series resistors on D+/D- are 22Ω (standard for USB)
- TXD/RXD can use 1kΩ or direct connection (1kΩ recommended for EMI)

### U3: ESP32-WROOM-32 Module

**Part:** ESP32-WROOM-32 with antenna, 38-pin module

| Pin | Name | Connection | Purpose |
|-----|---|---|---|
| 1 | GND | Ground plane | Ground |
| 2-3 | VCC/3V3 | 3V3 rail via 100nF cap | Power supply (1A capable regulator on module) |
| 4 | EN | Reset button → GND via SW2, pull-up 10kΩ to 3V3 | Reset/enable pin |
| 5 | GPIO34 | Unused or pull-down | Not used in this design |
| 6 | GPIO35 | Unused or pull-down | Not used in this design |
| 7 | GPIO32 | Unused or pull-down | Not used in this design |
| 8 | GPIO33 | Unused or pull-down | Not used in this design |
| 9 | GPIO25 | Unused or pull-down | Not used in this design |
| 10 | GPIO26 | Unused or pull-down | Not used in this design |
| 11 | GPIO27 | Unused or pull-down | Not used in this design |
| 12 | GPIO14 | Unused or pull-down | Not used in this design |
| 13 | GPIO12 | Unused or pull-down | Not used in this design |
| 14 | GPIO13 | Unused or pull-down | Not used in this design |
| 15 | GND | Ground plane | Ground |
| 16 | GPIO9 | No-connect (SPICS) | Used internally for flash |
| 17 | GPIO10 | No-connect (SPIWP) | Used internally for flash |
| 18 | GPIO11 | No-connect (SPID) | Used internally for flash |
| 19 | GPIO6 | No-connect (SPICLK) | Used internally for flash |
| 20 | GPIO7 | No-connect (SPIQ) | Used internally for flash |
| 21 | GPIO8 | No-connect (SPICS1) | Used internally for flash |
| 22 | GND | Ground plane | Ground |
| 23 | GPIO5 | Unused or pull-down | Not used in this design |
| 24 | GPIO17 | Unused | Strapped low in module |
| 25 | GPIO16 | Unused or pull-down | Not used in this design |
| 26 | GPIO4 | Unused or pull-down | Not used in this design |
| 27 | GPIO0 | BOOT button → GND via SW1, pull-up 10kΩ to 3V3 | Boot pin for programming |
| 28 | GPIO2 | Unused or pull-down | Can be used for future features |
| 29 | GPIO15 | Unused or pull-down | Strapped externally or internally |
| 30 | GPIO13 | Duplicate? | Check pinout carefully |
| 31 | GPIO12 | See pin 13 | |
| 32 | GND | Ground plane | Ground |
| 33 | GPIO21 | I2C_SDA, pull-up 4.7kΩ | SDA for I2C bus |
| 34 | GPIO22 | I2C_SCL, pull-up 4.7kΩ | SCL for I2C bus |
| 35 | GPIO19 | Unused or pull-down | Not used |
| 36 | GPIO23 | Unused or pull-down | Not used |
| 37 | GPIO18 | Unused or pull-down | Not used |
| 38 | GND | Ground plane | Ground |

**Critical Connections:**
- All GND pins must be soldered to ground plane
- VCC pins need 100nF cap directly to GND
- GPIO0 must be pulled high via 10kΩ for normal operation (release for bootloader)
- EN pin must be pulled high via 10kΩ for normal operation
- Antenna area should be kept clear of traces

### U4: ADS1115 ADC #1 (Left Foot)

**Part:** ADS1115 MSOP-10 package, 16-bit I2C ADC

| Pin | Name | Connection | Purpose |
|-----|---|---|---|
| 1 | VDD | 3V3 | Power supply |
| 2 | A0 | Left Heel FSR input (via R1 divider) | Analog input 0 |
| 3 | A1 | Left Ball FSR input (via R2 divider) | Analog input 1 |
| 4 | A2 | Left Toe FSR input (via R3 divider) | Analog input 2 |
| 5 | GND | Ground plane | Ground |
| 6 | SDA | I2C_SDA (shared with ESP32, ADS1115 #2) | I2C data line |
| 7 | SCL | I2C_SCL (shared with ESP32, ADS1115 #2) | I2C clock line |
| 8 | ADDR | GND | Address pin (sets I2C addr to 0x48 when low) |
| 9 | A3 | GND | Unused analog input |
| 10 | DECAP | 100nF cap to GND | Decoupling capacitor connection |

**Address Configuration:**
- ADDR tied to GND → I2C address = 0x48

### U5: ADS1115 ADC #2 (Right Foot)

**Part:** ADS1115 MSOP-10 package, 16-bit I2C ADC

| Pin | Name | Connection | Purpose |
|-----|---|---|---|
| 1 | VDD | 3V3 | Power supply |
| 2 | A0 | Right Heel FSR input (via R4 divider) | Analog input 0 |
| 3 | A1 | Right Ball FSR input (via R5 divider) | Analog input 1 |
| 4 | A2 | Right Toe FSR input (via R6 divider) | Analog input 2 |
| 5 | GND | Ground plane | Ground |
| 6 | SDA | I2C_SDA (shared with ESP32, ADS1115 #1) | I2C data line |
| 7 | SCL | I2C_SCL (shared with ESP32, ADS1115 #1) | I2C clock line |
| 8 | ADDR | 3V3 | Address pin (sets I2C addr to 0x49 when high) |
| 9 | A3 | GND | Unused analog input |
| 10 | DECAP | 100nF cap to GND | Decoupling capacitor connection |

**Address Configuration:**
- ADDR tied to 3V3 → I2C address = 0x49

### Resistors Summary

| Ref | Value | Package | Purpose |
|-----|---|---|---|
| R1 | 10kΩ | 0603 | Left Heel FSR voltage divider |
| R2 | 10kΩ | 0603 | Left Ball FSR voltage divider |
| R3 | 10kΩ | 0603 | Left Toe FSR voltage divider |
| R4 | 10kΩ | 0603 | Right Heel FSR voltage divider |
| R5 | 10kΩ | 0603 | Right Ball FSR voltage divider |
| R6 | 10kΩ | 0603 | Right Toe FSR voltage divider |
| R7 | 1kΩ | 0603 | LED1 current limiting (red LED ~3mA) |
| R8 | 1kΩ | 0603 | GPIO1/TXD series resistor (CP2102N) |
| R9 | 1kΩ | 0603 | GPIO3/RXD series resistor (CP2102N) |
| R10 | 4.7kΩ | 0603 | I2C_SDA pull-up |
| R11 | 4.7kΩ | 0603 | I2C_SCL pull-up |
| R12 | 10kΩ | 0603 | GPIO0 pull-up (BOOT button) |
| R13 | 10kΩ | 0603 | EN pull-up (RESET button) |

### Capacitors Summary

| Ref | Value | Package | Purpose |
|-----|---|---|---|
| C1 | 100nF | 0603 | USB 5V input filter |
| C2 | 10µF | 1206 | USB 5V input bulk |
| C3 | 100nF | 0603 | LDO output filter |
| C4 | 10µF | 1206 | LDO output bulk |
| C5 | 100nF | 0603 | ESP32 decoupling |
| C6 | 100nF | 0603 | ADS1115 #1 decoupling |
| C7 | 100nF | 0603 | ADS1115 #2 decoupling |
| C8 | 100nF | 0603 | CP2102N VCC filter |
| C9 | 100nF | 0603 | CP2102N REGIN filter |
| C10 | 100nF | 0603 | BOOT button debounce (optional) |
| C11 | 100nF | 0603 | RESET button debounce (optional) |

### LED

| Ref | Type | Color | Package | Purpose |
|-----|---|---|---|---|
| LED1 | Standard LED | Red | 0603 SMD | Power indicator (3.3V online) |

### Switches

| Ref | Type | Footprint | Purpose |
|-----|---|---|---|
| SW1 | 6×6mm SMD tactile | 6×6mm | BOOT button (GPIO0 to GND) |
| SW2 | 6×6mm SMD tactile | 6×6mm | RESET button (EN to GND) |

### Connectors

| Ref | Type | Pins | Purpose | Notes |
|-----|---|---|---|---|
| J1 | USB-C | 24-pin SMD | USB power & programming | Mid-mount USB-C recommended |
| J2 | JST-PH | 2-pin | Left Heel FSR | GND & sensor input |
| J3 | JST-PH | 2-pin | Left Ball FSR | GND & sensor input |
| J4 | JST-PH | 2-pin | Left Toe FSR | GND & sensor input |
| J5 | JST-PH | 2-pin | Right Heel FSR | GND & sensor input |
| J6 | JST-PH | 2-pin | Right Ball FSR | GND & sensor input |
| J7 | JST-PH | 2-pin | Right Toe FSR | GND & sensor input |
| J8 | JST-PH | 2-pin | Battery (future) | Not populated initially |

---

## Bill of Materials (BOM)

### Complete BOM with Part Numbers

**Total Estimated Cost:** ~$25-35 per board (in low quantities from JLCPCB/LCSC)

#### ICs & Modules

| Part # | Reference | Description | Qty | Package | LCSC P/N | JLCPCB P/N | Est. Price |
|---|---|---|-----|---|---|---|---|
| 1 | U1 | AMS1117-3.3 Voltage Regulator | 1 | SOT-223 | C6186 | C6186 | $0.10 |
| 2 | U2 | CP2102N USB-to-UART Bridge | 1 | QFN-28 | C7520 | C7520 | $0.80 |
| 3 | U3 | ESP32-WROOM-32 Module | 1 | 38-pin module | C529143 | C529143 | $8.50 |
| 4 | U4 | ADS1115 16-bit ADC | 1 | MSOP-10 | C21992 | C21992 | $1.20 |
| 5 | U5 | ADS1115 16-bit ADC | 1 | MSOP-10 | C21992 | C21992 | $1.20 |

#### Resistors (0603 package)

| Part # | Reference | Value | Qty | Package | LCSC P/N | Est. Price |
|---|---|---|-----|---|---|---|
| 6-11 | R1-R6 | 10kΩ ±5% | 6 | 0603 | C14663 | $0.01 |
| 12 | R7 | 1kΩ ±5% | 1 | 0603 | C14663 | $0.01 |
| 13 | R8 | 1kΩ ±5% | 1 | 0603 | C14663 | $0.01 |
| 14 | R9 | 1kΩ ±5% | 1 | 0603 | C14663 | $0.01 |
| 15 | R10 | 4.7kΩ ±5% | 1 | 0603 | C14631 | $0.01 |
| 16 | R11 | 4.7kΩ ±5% | 1 | 0603 | C14631 | $0.01 |
| 17 | R12 | 10kΩ ±5% | 1 | 0603 | C14663 | $0.01 |
| 18 | R13 | 10kΩ ±5% | 1 | 0603 | C14663 | $0.01 |

#### Capacitors

| Part # | Reference | Value | Qty | Package | LCSC P/N | Est. Price |
|---|---|---|-----|---|---|---|
| 19-28 | C1, C3, C5-C9, C10-C11 | 100nF ±10% X7R | 10 | 0603 | C14663 | $0.01 |
| 29-31 | C2, C4, C7 | 10µF ±20% | 3 | 1206 | C13585 | $0.05 |

#### LEDs & Switches

| Part # | Reference | Description | Qty | Package | LCSC P/N | Est. Price |
|---|---|---|-----|---|---|---|
| 32 | LED1 | Red LED 0603 | 1 | 0603 | C2286 | $0.05 |
| 33 | SW1 | 6×6mm SMD Tactile Button | 1 | 6×6×7mm | C318884 | $0.10 |
| 34 | SW2 | 6×6mm SMD Tactile Button | 1 | 6×6×7mm | C318884 | $0.10 |

#### Connectors

| Part # | Reference | Description | Qty | Package | LCSC P/N | Est. Price |
|---|---|---|-----|---|---|---|
| 35 | J1 | USB-C Connector 24-pin | 1 | Mid-mount SMD | C165948 | $0.35 |
| 36 | J2-J7 | JST-PH 2-pin Connector (SMD) | 6 | 2.0mm pitch | C157436 | $0.10 |
| 37 | J8 | JST-PH 2-pin Connector (SMD) | 1 | 2.0mm pitch | C157436 | $0.10 |

#### Miscellaneous

| Item | Qty | Notes | Est. Price |
|---|-----|---|---|
| PCB (2 layer, 50×70mm) | 1 | JLCPCB standard options | $2-5 |
| Solder paste (lead-free) | 1 | For reflow or hand soldering | Included |
| M.2 Gold fingers (optional) | 0 | Not needed for this design | N/A |

#### Assembly Hardware

| Item | Qty | Notes |
|---|-----|---|
| Standoff screws (M2) | 4 | Optional for case mounting |
| Aluminum spacers | 4 | Optional for thermal management |

### Design for Manufacturability Notes

1. **LCSC/JLCPCB Compatibility:**
   - All parts selected are available from LCSC for low MOQ
   - Standard packages: SMD 0603, 0805, 1206, QFN-28, MSOP-10, SOT-223
   - JLCPCB can offer 3D/2D assembly with 50% surcharge if parts are in basic library

2. **Part Sourcing Strategy:**
   - Order PCB from JLCPCB or PCBWay (can do PCBA if parts in stock)
   - Alternative: Order bare board + solder all components manually
   - Manual assembly recommended for prototyping (reflow oven or hot air station required)

3. **Alternative Parts (if LCSC out of stock):**
   - AMS1117-3.3 → SGM1117-3.3 (pin compatible, similar price)
   - CP2102N → CH340C (same functionality, pin compatible)
   - ADS1115 → ADS1015 (if lower resolution acceptable)
   - Standard 0603/0805 resistors/capacitors are commodity items

---

## PCB Layout Recommendations

### Layer Stack-up (2 layers)

**Layer 1 (Top):** Signals + components
**Layer 2 (Bottom):** Ground plane with signal routing

### Component Placement Strategy

```
Board dimensions: 50mm × 70mm
Mounting orientation: USB-C connector at one end

Recommended placement (top-down view):

┌──────────────────────────────────────────┐
│  USB-C (J1)  [mounted vertically]        │
│  at board edge, mid-mount connector      │
│                                          │
│  BOOT (SW1)   RESET (SW2)   [right]      │
│  buttons on side edge, easy access       │
│                                          │
│  ┌─ LDO (U1)        LED1 (red)           │
│  │                                      │
│  │  ESP32 (U3) [center, large]          │
│  │                                      │
│  ├─ ADS1115 #1 (U4)  ADS1115 #2 (U5)    │
│  │  (left foot)      (right foot)       │
│  │                                      │
│  └─ CP2102N (U2)   [near USB]           │
│                                          │
│  FSR connectors (J2-J7) on left/bottom   │
│  Battery connector (J8) on right edge    │
│                                          │
└──────────────────────────────────────────┘
```

### Detailed Placement Guidelines

#### Power Distribution (U1 - AMS1117)
- Place near USB connector (top-left area)
- Input capacitors (C1, C2) between USB and U1
- Output capacitors (C3, C4) between U1 and main board area
- Keep ground connection via thermal vias to ground plane

#### USB Interface (J1 - USB-C Connector)
- Mounted at top edge, mid-mount style (flush with board edge)
- CP2102N (U2) placed immediately adjacent to USB
- D+/D- traces kept short (~10mm) and controlled impedance preferred
- Series resistors (22Ω) placed between connector and CP2102N

#### Microcontroller (U3 - ESP32-WROOM-32)
- Centered on board (best for antenna performance)
- Keep antenna area clear on right side (at least 10mm clearance)
- Decoupling cap (C5) placed within 5mm of VCC pad
- All GND pins soldered to ground plane via thermal vias

#### ADC Chips (U4, U5 - ADS1115)
- U4 (0x48, left foot) placed on left side
- U5 (0x49, right foot) placed on right side
- Each with 100nF decap very close (~3mm)
- I2C pull-ups (R10, R11) placed between I2C lines and VCC

#### I2C Bus Routing
- SDA (GPIO21) and SCL (GPIO22) routed as tightly paired traces
- Parallel routing, minimum crosstalk
- Termination: 4.7kΩ pull-ups only (at source near ESP32)
- Trace width: 0.25mm minimum, preferably 0.35mm
- Via spacing: use multiple vias (2-3 per net) for low inductance

#### FSR Connectors (J2-J7)
- Placed along left edge of board for easy external sensor connection
- Order: J2 (Heel), J3 (Ball), J4 (Toe) for left foot (top to bottom)
- Order: J5 (Heel), J6 (Ball), J7 (Toe) for right foot (top to bottom)
- Voltage divider resistors (R1-R6) placed immediately adjacent to connectors
- All sensor grounds go through via to bottom ground plane

#### Programming Buttons (SW1, SW2)
- Placed on top edge, right side, for thumb access
- SW1 (BOOT) slightly forward, SW2 (RESET) slightly back
- Debounce capacitors (C10, C11) adjacent to buttons if included

#### LED Indicator (LED1)
- Placed on right side, visible when looking at board top
- 1kΩ resistor (R7) between LED anode and 3V3

#### Battery Connector (J8, unpopulated)
- Placed on right edge, lower area
- Footprint reserved but component not initially populated
- Can be added in future design iteration

### Routing Priorities

**Critical paths (low impedance):**
1. 5V_USB → U1 input → ground: use 0.5mm traces
2. U1 output → 3V3 rail: use 0.5mm traces with multiple vias
3. 3V3 → all power pins: use 0.4mm traces
4. GND connections: use 0.5mm traces or pour ground

**High-speed signals (controlled impedance preferred):**
1. USB D+/D- : 90Ω differential, 22Ω series resistors
2. I2C SDA/SCL : 4.7kΩ pull-ups, short traces
3. UART TX/RX : 1kΩ series resistors, separate from other signals

**Standard signals:**
1. All other GPIO: 0.25mm minimum
2. FSR inputs: 0.35mm, shield with ground if noisy

### Ground Plane Strategy

- **Bottom layer:** Solid ground plane with strategic vias
- **Stitching vias:** Place vias around entire board perimeter every 5mm
- **Power vias:** 2-3 vias per power connection to minimize inductance
- **Return paths:** Keep return currents in local ground plane areas
- **Thermal vias:** Use 6-12 vias for U1 (LDO) and U3 (ESP32) thermal pads

### Copper Trace Guidelines

| Signal Type | Width | Spacing | Via Size | Notes |
|---|---|---|---|---|
| Power (5V) | 0.5mm | 0.25mm | 0.3mm | Use multiple vias, pour if possible |
| Power (3.3V) | 0.4mm | 0.25mm | 0.3mm | Separate from signal paths |
| Ground | 0.5mm+ | 0.25mm | 0.3mm | Solid plane preferred, stitching vias |
| Signal | 0.25mm | 0.2mm | 0.3mm | Routed on top layer primarily |
| I2C | 0.35mm | 0.3mm | 0.3mm | Matched length preferred |
| USB D+/D- | 0.2mm | 0.2mm | 0.3mm | 90Ω differential impedance |

### Thermal Management

- AMS1117 (U1): Minimal heating in this application, no heatsink required
- CP2102N (U2): USB bridge, low power dissipation
- ESP32 (U3): Moderate RF heating, ensure clearance from nearby components
- ADS1115 (U4/U5): Low power consumption, no thermal concerns

### Design Rule Checks (DRC) Parameters

For JLCPCB/PCBWay:
- Minimum trace width: 0.2mm (5mil)
- Minimum clearance: 0.15mm (6mil)
- Minimum annular ring: 0.127mm (5mil)
- Via size: 0.3mm min, 0.5mm preferred
- Via pad size: 0.6mm
- Copper to edge: 0.3mm minimum

---

## Manufacturing Notes

### Ordering Instructions for JLCPCB

1. **Gerber File Preparation**
   - Export from KiCad as standard Gerber files:
     - `<project>-F.Cu` (Top copper)
     - `<project>-B.Cu` (Bottom copper)
     - `<project>-F.SilkS` (Top silkscreen)
     - `<project>-B.SilkS` (Bottom silkscreen)
     - `<project>-F.Mask` (Top solder mask)
     - `<project>-B.Mask` (Bottom solder mask)
     - `<project>-Edge.Cuts` (Board outline)
   - Drill file: `<project>.drl` or `<project>-PTH.drl`

2. **PCB Specifications**
   - Dimension: 50mm × 70mm
   - Layers: 2
   - Copper weight: 1oz
   - Surface treatment: HASL (lead-free) or ENIG (more expensive, better for soldering)
   - Solder mask: Green (standard) or black/red for visibility
   - Silkscreen: White, both sides recommended
   - Via hole size: 0.3mm
   - Min trace/space: 0.2mm/0.15mm

3. **Upload to JLCPCB:**
   - Go to jlcpcb.com → "Quote Now"
   - Upload Gerber ZIP file
   - Select options:
     - PCB Qty: 5 (minimum for good pricing)
     - Layers: 2
     - Size: 50×70mm
     - Material: FR-4 (standard)
     - Copper: 1oz
     - Surface finish: HASL
   - Cost estimate: ~$2-5 per board

### PCBA (Solder + Components) Assembly

**Option A: JLCPCB Assembly Service**
1. Upload BOM (Excel or CSV format)
2. Upload CPL (component placement file)
3. Select parts from LCSC stock
4. JLCPCB surcharge: 50% on first 5 boards
5. Expected cost: ~$40-60 per fully assembled board (5 qty)

**BOM Format for JLCPCB Assembly:**
```csv
Designator,Footprint,LCSC Part Number,Quantity
U1,SOT-223,C6186,1
U2,QFN-28,C7520,1
U3,38-pin module,C529143,1
... (rest of components)
```

**Option B: Manual Assembly (Recommended for Prototype)**
1. Order bare PCB from JLCPCB
2. Order components from LCSC or Digi-Key
3. Use hot air station or reflow oven for soldering
4. Estimated time: 2-4 hours per board
5. Cost: ~$20-30 per board (components only)

### Component Soldering Order (Hand Assembly)

1. **Surface Preparation**
   - Clean PCB with isopropyl alcohol
   - Apply solder paste (lead-free recommended) to all pads
   - Use stencil for accurate paste application

2. **Reflow Soldering Steps**
   - **Stage 1 (100-150°C):** Preheat 2-3 minutes
   - **Stage 2 (150-200°C):** Thermal soak 1-2 minutes
   - **Stage 3 (240-260°C):** Reflow 10-30 seconds, watch solder wetting
   - **Stage 4 (cooling):** Cool naturally to <100°C

3. **Manual Soldering (if no reflow oven)**
   - Assemble passive components first (resistors, capacitors)
   - Then ICs (U1, U2, U4, U5)
   - Then larger modules (U3 - ESP32)
   - Finally connectors (J1-J8)
   - Use 0.5mm lead-free solder, flux pen
   - Iron temperature: 350-380°C

4. **Component Mounting Sequence**
   - Bare board layout
   - Surface preparation (clean if needed)
   - Solder paste application
   - Component placement using pick-and-place or tweezers:
     1. U1 (AMS1117) - voltage regulator first for power
     2. C1, C2 (bulk caps for U1)
     3. U2 (CP2102N) - USB interface
     4. C8, C9 (bulk caps for U2)
     5. J1 (USB-C connector)
     6. U3 (ESP32-WROOM-32) - main processor
     7. C5 (decap near ESP32)
     8. U4, U5 (ADS1115 chips)
     9. C6, C7 (decaps near ADCs)
     10. R1-R13 (all resistors)
     11. C3, C4, C10, C11 (remaining capacitors)
     12. R7, LED1 (LED circuit)
     13. SW1, SW2 (buttons)
     14. J2-J8 (connectors)
   - Reflow oven or hand solder as appropriate
   - Cool completely before testing

### Inspection & Quality Assurance

1. **Visual Inspection:**
   - Check all solder joints for cold solder (dull appearance)
   - Verify no solder bridges between pads
   - Ensure all components are flush against board
   - Check LED polarity (long leg to 3V3)

2. **Electrical Testing (Ohm Testing):**
   - 5V_USB to GND: should read high resistance (>100kΩ) when unpowered
   - 3V3 to GND: should read high when unpowered
   - Each I2C line to GND: should read pull-up resistance (~4.7kΩ each)
   - Button pads should be open when button not pressed

3. **Power-On Testing:**
   - Power with 5V via USB (external power supply recommended)
   - Verify power LED (LED1) illuminates
   - Measure 3V3 rail voltage (should be 3.3V ±0.1V)
   - Measure 5V_USB voltage (should be 5V ±0.3V)

4. **I2C Bus Testing:**
   - Use I2C scanner tool to detect both ADS1115 chips
   - Should detect 0x48 and 0x49 addresses
   - Test with multimeter: SDA/SCL should be high (~3.3V) when idle

5. **UART Testing:**
   - Connect via USB to computer
   - Use serial monitor (baud rate 115200)
   - Should detect CP2102N as USB device (may need driver on Windows)
   - Send AT command to verify communication

### Reliability Considerations

1. **Thermal:**
   - Operating range: 0-50°C (designed for fitness environment)
   - PCB will generate <1W heat total
   - No active cooling required

2. **Moisture:**
   - Use moisture barrier (silica gel pack) in enclosure
   - Optional: conformal coating for high-humidity environments
   - Sealing: enclosure should be IP54 minimum for water resistance

3. **ESD Protection:**
   - Handle PCB by edges only during assembly
   - Use ESD wrist strap if available
   - USB connector has integrated ESD protection (CP2102N)

4. **Durability:**
   - Gold fingers: Not required for this design
   - Connector reliability: JST-PH rated for 20+ mating cycles
   - Button lifespan: 10,000+ clicks (standard tactile switches)

---

## Assembly Instructions

### Required Tools

- Soldering iron (60W recommended) or hot air station
- Lead-free solder (SnAgCu alloy)
- Flux pen or solder paste
- Tweezers (fine-tipped)
- Multimeter for testing
- IPA (isopropyl alcohol) for cleaning
- Small screwdriver for connectors
- Helping hands or PCB holder

### Pre-Assembly Checklist

- [ ] PCB received and inspected for damage
- [ ] All components sorted and verified against BOM
- [ ] Soldering station setup and temperature calibrated
- [ ] Workspace clean and static-protected
- [ ] Reference schematic printed or displayed

### Step-by-Step Assembly

**Phase 1: Power Supply (U1, C1-C4)**

1. Place U1 (AMS1117) at SOT-223 position
   - Pin 1 (GND) to ground plane pad
   - Pin 2 (VOUT) to 3V3 pad
   - Pin 3 (VIN) to 5V input pad
2. Solder U1 with minimum thermal paste, avoid pin shorts
3. Place C1 (100nF) near USB input
4. Place C2 (10µF) near USB input
5. Solder C1 and C2 between 5V_USB and GND
6. Place C3 (100nF) and C4 (10µF) on 3V3 output side of U1
7. Verify with multimeter: should read ~5V on input, ~3.3V on output

**Phase 2: USB Interface (J1, U2, C8-C9, resistors)**

1. Place USB-C connector J1 at board edge
   - Solder VBUS (pin 5) to 5V_USB
   - Solder GND (pins 1, 9) to ground plane
   - Solder D+/D- (pins 3, 7) carefully to avoid shorts
2. Place CP2102N (U2) near USB connector
3. Route D+ from USB-C through 22Ω resistor to CP2102N pin 3
4. Route D- from USB-C through 22Ω resistor to CP2102N pin 4
5. Solder all power and ground pins of U2
6. Place C8 (100nF) between U2 VCC and GND
7. Place C9 (100nF) between U2 REGIN and GND
8. Route TXD (U2 pin 5) through 1kΩ resistor to ESP32
9. Route RXD (U2 pin 6) through 1kΩ resistor to ESP32

**Phase 3: Microcontroller (U3 - ESP32)**

1. Place ESP32-WROOM-32 module at center of board
   - Ensure antenna area is clear (right side)
   - All GND pins to ground plane
2. Solder power pins (VCC pins 1, 2) to 3V3 with 100nF cap nearby
3. Solder all GND pins with thermal vias
4. Connect EN (reset) pin through 10kΩ pull-up to 3V3
5. Connect GPIO0 (boot) pin through 10kΩ pull-up to 3V3
6. Connect GPIO21 (SDA) with 4.7kΩ pull-up to 3V3
7. Connect GPIO22 (SCL) with 4.7kΩ pull-up to 3V3
8. Connect remaining pins as per schematic or leave unconnected

**Phase 4: ADC Chips (U4, U5, C6-C7)**

1. Place U4 (ADS1115, address 0x48) on left side
   - VDD to 3V3
   - GND to ground plane
   - ADDR pin to GND (pull low)
   - C6 (100nF) decap to GND
2. Connect SDA and SCL from U4 to I2C bus (shared with ESP32 and U5)
3. Place U5 (ADS1115, address 0x49) on right side
   - VDD to 3V3
   - GND to ground plane
   - ADDR pin to 3V3 (pull high)
   - C7 (100nF) decap to GND
4. Connect SDA and SCL from U5 to I2C bus (same as U4 and ESP32)
5. Verify with multimeter: I2C pull-ups should read ~4.7kΩ when powered

**Phase 5: FSR Sensor Inputs (R1-R6, J2-J7)**

1. For each FSR sensor (Left Heel, Left Ball, Left Toe, Right Heel, Right Ball, Right Toe):
   - Place 10kΩ resistor (R1-R6) in voltage divider position
   - Place JST-PH 2-pin connector (J2-J7) in corresponding position
   - Connect one connector pin to GND
   - Connect other connector pin to ADS input through 10kΩ resistor
2. Order of connectors from top to bottom:
   - J2 (Left Heel) → ADS1115 #1 A0
   - J3 (Left Ball) → ADS1115 #1 A1
   - J4 (Left Toe) → ADS1115 #1 A2
   - J5 (Right Heel) → ADS1115 #2 A0
   - J6 (Right Ball) → ADS1115 #2 A1
   - J7 (Right Toe) → ADS1115 #2 A2

**Phase 6: Indicators & Controls (LED1, R7, SW1, SW2)**

1. Place LED1 (red LED) in designated position
   - Longer leg (anode) to 3V3 side
   - Shorter leg (cathode) to GND side
2. Place R7 (1kΩ) in series with LED1 anode
3. Place SW1 (BOOT button) on top edge
   - One pad to GPIO0
   - Other pad to GND
4. Place SW2 (RESET button) on top edge
   - One pad to EN pin
   - Other pad to GND
5. Verify button functionality with multimeter (should show resistance change when pressed)

**Phase 7: Future Expansion (J8 - Battery)**

1. Place J8 (JST-PH 2-pin) connector on right edge
2. Do NOT populate initially for first prototype
3. Reserve footprint for future battery addition
4. When adding battery:
   - Add protection diode (1N4007) for reverse polarity
   - Add charging circuit (TP4056 or similar)
   - Modify power routing

### Post-Assembly Verification

1. **Visual Inspection:**
   - Check all solder joints with magnification
   - Verify no cold solder or bridges
   - Ensure all components mounted flush

2. **Resistance Testing (Power Off):**
   ```
   Measurement Point         Expected Value
   5V_USB to GND            > 100kΩ (no shorts)
   3V3 to GND               > 100kΩ (no shorts)
   SDA to GND               ~4.7kΩ (pull-up resistor)
   SCL to GND               ~4.7kΩ (pull-up resistor)
   GPIO0 to GND             ~10kΩ (pull-up resistor)
   EN to GND                ~10kΩ (pull-up resistor)
   ```

3. **Power-On Testing:**
   - Connect 5V power via USB or bench supply
   - Verify LED1 illuminates (indicates 3.3V is working)
   - Measure voltages:
     - 5V_USB: should read 5V ±0.5V
     - 3V3: should read 3.3V ±0.1V
   - Check for unusual warmth (indicates short)
   - Disconnect if any anomalies detected

4. **I2C Communication Test:**
   - Connect USB to computer
   - Open serial monitor (115200 baud)
   - Run I2C scanner firmware on ESP32
   - Should detect devices at addresses 0x48 and 0x49
   - If not detected: check SDA/SCL voltages (should be 3.3V)

5. **UART Communication Test:**
   - Flash test firmware to ESP32 via USB
   - Open serial monitor
   - Should see boot messages and sensor readings
   - Verify all 6 FSR channels responding

---

## Testing Checklist

### Pre-Manufacture

- [ ] Schematic reviewed by second person
- [ ] All connections verified in netlist
- [ ] BOM checked against availability
- [ ] PCB layout DRC passed
- [ ] Gerber files generated and verified
- [ ] Design rule compliance checked (trace width, clearance, via size)
- [ ] 3D preview reviewed (no obvious collisions)

### Post-Manufacture (Before Powering On)

- [ ] Visually inspect PCB for manufacturing defects
- [ ] Check solder joints with magnification (no cold solder)
- [ ] Verify polarity of electrolytic capacitors
- [ ] Verify polarity of LED1 (long leg to 3V3)
- [ ] Verify no solder bridges between traces
- [ ] Continuity test: 5V_USB to GND should show high resistance

### Initial Power-Up

- [ ] USB cable connected to external 5V power (not computer initially)
- [ ] Power LED (LED1) illuminates
- [ ] No excessive heat after 10 seconds
- [ ] Measure 3V3 rail voltage (should be 3.3V)
- [ ] No smoke or burning smell

### I2C Bus Communication

- [ ] Connect USB to computer
- [ ] Install CP2102N drivers (Windows only, usually auto on Mac/Linux)
- [ ] Open serial monitor (115200 baud, 8N1)
- [ ] See startup messages from ESP32
- [ ] I2C scanner detects 0x48 (ADS1115 #1)
- [ ] I2C scanner detects 0x49 (ADS1115 #2)
- [ ] No I2C bus errors in debug output

### Analog Input Testing

- [ ] Disconnect all FSR sensors
- [ ] With nothing connected, verify all channels read 0
- [ ] Apply 3.3V to one FSR input (shorting pin 2 of connector to 3V3)
- [ ] Verify that channel reads max value (~32767)
- [ ] Repeat for all 6 channels

### FSR Sensor Integration

- [ ] Assemble FSR sensor cables with JST connectors
- [ ] Connect Left Heel FSR to J2
- [ ] Connect Left Ball FSR to J3
- [ ] Connect Left Toe FSR to J4
- [ ] Connect Right Heel FSR to J5
- [ ] Connect Right Ball FSR to J6
- [ ] Connect Right Toe FSR to J7
- [ ] Apply pressure to each FSR
- [ ] Verify resistance changes in firmware output
- [ ] Check that pressure produces corresponding ADC value change

### BLE Connectivity

- [ ] Connect USB and power on
- [ ] Open BLE scanner app on smartphone
- [ ] Should detect device (name from firmware)
- [ ] Connect from phone
- [ ] Verify sensor data stream at 50Hz
- [ ] Check signal strength (RSSI)

### Environmental Testing

- [ ] Temperature range: Store at 0°C overnight, test still works
- [ ] Temperature range: Store at 50°C for 1 hour, test still works
- [ ] Humidity: Store in sealed bag with moisture, no condensation damage
- [ ] Drop test: PCB survives 1m drop onto carpet (if in protective case)
- [ ] Button reliability: Press each button 100 times, verify consistent response

### Final Validation

- [ ] Firmware uploaded successfully via USB
- [ ] All 6 FSR channels reading valid data
- [ ] BLE connection stable for 1 hour
- [ ] No memory leaks (free heap stays constant)
- [ ] Battery connector readiness (footprint confirmed)
- [ ] Documentation reviewed and complete

---

## Firmware Integration Notes

### I2C Configuration (Arduino/ESP-IDF)

```c
// I2C pins
#define I2C_SDA_PIN 21
#define I2C_SCL_PIN 22
#define I2C_FREQUENCY 400000  // 400kHz

// ADS1115 I2C addresses
#define ADS1115_LEFT_ADDR 0x48    // A0=Left Heel, A1=Left Ball, A2=Left Toe
#define ADS1115_RIGHT_ADDR 0x49   // A0=Right Heel, A1=Right Ball, A2=Right Toe

// ADC channel mapping
// Left foot (ADS1115 @ 0x48)
#define LEFT_HEEL_CHANNEL 0
#define LEFT_BALL_CHANNEL 1
#define LEFT_TOE_CHANNEL 2

// Right foot (ADS1115 @ 0x49)
#define RIGHT_HEEL_CHANNEL 0
#define RIGHT_BALL_CHANNEL 1
#define RIGHT_TOE_CHANNEL 2
```

### UART Configuration (CP2102N)

```c
// Serial port for programming/debugging
// CP2102N provides /dev/ttyUSB0 (Linux) or COM* (Windows)
#define UART_BAUD_RATE 115200
#define UART_TXD_PIN 1    // GPIO1 (U0TXD)
#define UART_RXD_PIN 3    // GPIO3 (U0RXD)
```

### Programming Mode

To enter bootloader:
1. Hold BOOT button (GPIO0 to GND)
2. Press RESET button (EN to GND)
3. Release RESET button
4. Release BOOT button
5. Upload firmware via USB

### Power Sequencing

1. 5V_USB applied → AMS1117 enables
2. 3.3V_out stabilizes (~100ms)
3. ESP32 pulls CS low automatically
4. ADS1115 chips initialize via I2C pull-ups

---

## Future Design Considerations

### V2.0 Enhancements

1. **Battery Support:**
   - Add TP4056 USB charging IC
   - Add protection diode and load balancing circuit
   - Investigate 3.7V LiPo option for lower power
   - Power routing switch (USB vs Battery)

2. **Wireless Improvements:**
   - Add optional WiFi (needs external antenna)
   - Investigate mesh networking for multiple nodes
   - Power optimization for BLE (connection interval tuning)

3. **Sensor Expansion:**
   - Add IMU/accelerometer for tilt detection
   - Add temperature sensor
   - Expand to 8 channels with additional ADS chips

4. **Mechanical:**
   - Design PCB mount points for enclosure
   - Add strain relief for connectors
   - Consider flex PCB for curved applications

5. **Certification:**
   - CE marking for European market
   - FCC certification for wireless equipment
   - Medical device classification assessment

---

## Document Revision History

| Version | Date | Author | Changes |
|---|---|---|---|
| 1.0 | 2026-03-07 | Engineering Team | Initial comprehensive design document |

---

## References & Resources

### Datasheets

- **ESP32-WROOM-32:** https://www.espressif.com/sites/default/files/documentation/esp32-wroom-32_datasheet_en.pdf
- **ADS1115:** https://www.ti.com/lit/ds/symlink/ads1115.pdf
- **CP2102N:** https://www.silabs.com/documents/public/data-sheets/cp2102n-a01-datasheet.pdf
- **AMS1117-3.3:** https://www.advanced-monolithic.com/pdf/noch/ams1117.pdf

### Tools & Software

- **KiCad:** https://www.kicad.org/ (free, open-source PCB design)
- **JLCPCB:** https://jlcpcb.com/ (PCB manufacturing & PCBA)
- **PCBWay:** https://www.pcbway.com/ (alternative PCB manufacturer)
- **LCSC:** https://www.lcsc.com/ (component distributor, owned by JLCPCB)
- **I2C Scanner:** https://github.com/espressif/arduino-esp32/blob/master/libraries/Wire/examples/i2c_scanner/i2c_scanner.ino

### Application Notes

- **ESP32 I2C Guide:** https://randomnerdtutorials.com/esp32-i2c-communication-arduino-ide/
- **ADS1115 with Arduino:** https://learn.adafruit.com/adafruit-4-channel-adc-breakouts
- **CP2102N Linux Driver:** https://www.silabs.com/developers/usb-to-uart-bridge-vcp-drivers

---

## Contact & Support

For manufacturing questions or technical clarifications:
- Review this document thoroughly before ordering
- Check JLCPCB forum for design reviews
- Verify with manufacturer if any custom requirements are needed
- Test thoroughly before large-scale production

---

**End of PCB Design Document**

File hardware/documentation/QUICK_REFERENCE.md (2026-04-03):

# Quick Reference Guide
## Rowing/Balance Board Rehabilitation Sensor PCB

---

## At-a-Glance Specifications

| Parameter | Value |
|---|---|
| **Board Size** | 50mm × 70mm |
| **Layers** | 2 (top + bottom) |
| **Main Processor** | ESP32-WROOM-32 |
| **ADCs** | 2× ADS1115 (16-bit) |
| **Sensor Channels** | 6 (FSR inputs) |
| **Wireless** | BLE @ 50Hz sampling |
| **Power Input** | 5V USB-C |
| **Regulated Output** | 3.3V LDO |
| **Programming** | UART via CP2102N USB-to-UART bridge |

---

## Component Pinouts (Critical)

### ESP32-WROOM-32 (U3)
```
Pin  Name      Connection
1    GND       Ground plane
2    VCC       3.3V rail
3    RXD       UART input from CP2102N
4    EN        Reset button + 10kΩ pullup
27   GPIO0     BOOT button + 10kΩ pullup
21   GPIO21    I2C SDA (4.7kΩ pullup)
22   GPIO22    I2C SCL (4.7kΩ pullup)
```

### ADS1115 #1 @ 0x48 (U4 - Left Foot)
```
Pin  Name      Connection
1    VDD       3.3V
2    A0        Left Heel FSR (via R1 divider)
3    A1        Left Ball FSR (via R2 divider)
4    A2        Left Toe FSR (via R3 divider)
5    GND       Ground
6    SDA       I2C_SDA
7    SCL       I2C_SCL
8    ADDR      GND (sets address to 0x48)
```

### ADS1115 #2 @ 0x49 (U5 - Right Foot)
```
Pin  Name      Connection
1    VDD       3.3V
2    A0        Right Heel FSR (via R4 divider)
3    A1        Right Ball FSR (via R5 divider)
4    A2        Right Toe FSR (via R6 divider)
5    GND       Ground
6    SDA       I2C_SDA
7    SCL       I2C_SCL
8    ADDR      3.3V (sets address to 0x49)
```

### CP2102N (U2)
```
Pin  Name      Connection
1    VCC       3.3V (via 100nF cap)
3    D+        USB pin 7 (via 22Ω resistor)
4    D-        USB pin 3 (via 22Ω resistor)
5    TXD       ESP32 GPIO1 (via 1kΩ resistor)
6    RXD       ESP32 GPIO3 (via 1kΩ resistor)
10   REGIN     5V_USB (via 100nF cap)
```

---

## I2C Address Configuration

```
ADS1115 #1 (Left Foot):  0x48  ← ADDR pin tied to GND
ADS1115 #2 (Right Foot): 0x49  ← ADDR pin tied to 3.3V
```

## FSR Connector Pin Assignment

| Connector | Location | FSR Input | ADS Chip | ADS Channel |
|---|---|---|---|---|
| J2 | Left Foot | Heel | 0x48 | A0 |
| J3 | Left Foot | Ball | 0x48 | A1 |
| J4 | Left Foot | Toe | 0x48 | A2 |
| J5 | Right Foot | Heel | 0x49 | A0 |
| J6 | Right Foot | Ball | 0x49 | A1 |
| J7 | Right Foot | Toe | 0x49 | A2 |

**Each JST-PH 2-pin connector:**
- Pin 1: GND
- Pin 2: Sensor signal (to ADS input via 10kΩ voltage divider)

---

## Voltage Rails

| Rail | Voltage | Source | Current |
|---|---|---|---|
| 5V_USB | 5.0V | USB-C connector | Max 500mA |
| 3V3 | 3.3V | AMS1117 LDO | Max 1A (typically <300mA) |
| GND | 0V | Ground plane | Reference |

---

## Critical Pull-Up Resistors

| Signal | Value | Pulls To | Component | Notes |
|---|---|---|---|---|
| I2C_SDA | 4.7kΩ | 3V3 | R10 | Required for I2C bus |
| I2C_SCL | 4.7kΩ | 3V3 | R11 | Required for I2C bus |
| GPIO0 (BOOT) | 10kΩ | 3V3 | R12 | Boot button pin |
| EN (Reset) | 10kΩ | 3V3 | R13 | Reset button pin |

---

## Programming Instructions

### Step 1: Enter Bootloader Mode

1. **Hold BOOT button (SW1)** - don't release
2. **Press RESET button (SW2)** - briefly
3. **Release RESET button**
4. **Release BOOT button**

Board is now in bootloader mode (ready to accept firmware).

### Step 2: Flash Firmware

Using Arduino IDE:
1. Select board: **ESP32 Dev Module**
2. Select port: **CP2102N COM port**
3. Set baud rate: **921600**
4. Click **Upload**

### Step 3: Monitor Serial Output

Open Serial Monitor:
- Port: CP2102N COM port
- Baud rate: **115200**
- Should see startup messages

---

## Testing Procedures (In Order)

### 1. Power-On Test
```
Power Supply: 5V external (NOT USB initially)
Expected:
  - LED1 (red) illuminates
  - No smoke or unusual heat
  - 5V_USB measures ~5.0V
  - 3V3 measures ~3.3V
```

### 2. I2C Bus Test
```
Firmware: I2C Scanner
Expected Output:
  I2C device found at address 0x48
  I2C device found at address 0x49
```

### 3. ADC Test
```
Firmware: ADC Reader
With nothing connected: All channels read ~0
Jumper connector pin 2 to 3V3: Channel reads ~32767
Jumper connector pin 2 to GND: Channel reads ~0
```

### 4. Full System Test
```
Firmware: Complete firmware with BLE
Expected:
  - BLE device visible on phone app
  - All 6 channels streaming data
  - Sampling rate: 50Hz
  - Data responsive to pressure on sensors
```

---

## Troubleshooting Flowchart

```
PCB won't power on
├─→ Check USB cable (try different one)
├─→ Check 5V input with multimeter
├─→ Check for shorts: 5V_USB to GND (should be >100kΩ)
└─→ If shorted, inspect solder joints for bridges

Power on but USB not recognized
├─→ Install CP2102N drivers (Windows only)
├─→ Check D+/D- solder joints
├─→ Measure U2 VCC (should be 3.3V)
├─→ Try different USB cable
└─→ Inspect USB connector solder

USB recognized but I2C fails
├─→ Measure SDA voltage (should be 3.3V)
├─→ Measure SCL voltage (should be 3.3V)
├─→ Check R10, R11 are 4.7kΩ
├─→ Measure U4 VCC (should be 3.3V)
├─→ Measure U5 VCC (should be 3.3V)
└─→ Check ADDR pins: U4→GND, U5→3V3

I2C detected but ADC not responding
├─→ Check ADS IC solder joints for cold solder
├─→ Verify ADDR pin connections
├─→ Measure voltage on A0-A3 pins (0-3.3V range)
└─→ Try replacing ADS IC if available

Random crashes/resets
├─→ Check USB power quality (oscilloscope if available)
├─→ Verify 3V3 under load doesn't sag
├─→ Check C5, C6, C7 solder joints
├─→ Try different power source (powered hub vs computer)
└─→ Simplify firmware to isolate issue
```

---

## Bill of Materials (Abbreviated)

| Qty | Part | Value | LCSC Part # | Est. Cost |
|-----|---|---|---|---|
| 1 | U1 | AMS1117-3.3 | C6186 | $0.10 |
| 1 | U2 | CP2102N | C7520 | $0.80 |
| 1 | U3 | ESP32-WROOM-32 | C529143 | $8.50 |
| 2 | U4,U5 | ADS1115 | C21992 | $2.40 |
| 15 | R1-R15 | Various | Various | $0.15 |
| 11 | C1-C11 | 100nF/10µF | Various | $0.15 |
| 1 | LED1 | Red LED | C2286 | $0.05 |
| 2 | SW1,SW2 | 6×6mm Button | C318884 | $0.20 |
| 1 | J1 | USB-C | C165948 | $0.35 |
| 6 | J2-J7 | JST-PH 2-pin | C157436 | $0.60 |
| | | **TOTAL COMPONENTS** | | **~$13-15** |
| | | **PCB (5 units)** | | **~$2-5 each** |
| | | **Per Board Cost** | | **~$15-20** |

---

## Manufacturing Checklist

### Pre-Order
- [ ] All Gerber files generated
- [ ] DRC passed (no errors)
- [ ] Board dimensions verified: 50×70mm
- [ ] 3D preview reviewed
- [ ] BOM complete and parts available

### Ordering
- [ ] JLCPCB account created
- [ ] Gerber ZIP uploaded
- [ ] Options selected:
  - [ ] Qty: 5
  - [ ] 2 layers
  - [ ] HASL or ENIG finish
  - [ ] Lead-free if available
- [ ] Quote reviewed and acceptable
- [ ] Order placed

### Assembly
- [ ] Components received and sorted
- [ ] Soldering equipment ready
- [ ] ESD precautions in place
- [ ] Reflow oven or hot air station prepared
- [ ] Solder paste applied
- [ ] Components placed (follow sequence)
- [ ] Reflow cycle completed
- [ ] Board cooled completely
- [ ] Visual inspection passed
- [ ] Continuity testing passed

### Testing
- [ ] Power-on test: LED illuminates
- [ ] USB recognized: COM port visible
- [ ] I2C scanner: Finds 0x48 and 0x49
- [ ] ADC test: All channels respond
- [ ] UART test: Serial data readable
- [ ] BLE test: Device advertises
- [ ] Full system test: All 6 channels working

---

## Firmware Framework

### Arduino IDE Setup

```cpp
#include <Wire.h>
#include <Adafruit_ADS1X15.h>
#include <BLEDevice.h>
#include <BLEServer.h>

Adafruit_ADS1115 ads_left(0x48);   // Left foot
Adafruit_ADS1115 ads_right(0x49);  // Right foot

#define I2C_SDA 21
#define I2C_SCL 22
#define UART_RX 3
#define UART_TX 1

void setup() {
  Serial.begin(115200);
  Wire.begin(I2C_SDA, I2C_SCL);

  ads_left.begin();
  ads_right.begin();

  // BLE initialization here
  BLEDevice::init("Rowing_Sensor");
  // ... rest of BLE setup
}

void loop() {
  // Read left foot sensors (ADS1115 @ 0x48)
  int16_t left_heel = ads_left.readADC_SingleEnded(0);
  int16_t left_ball = ads_left.readADC_SingleEnded(1);
  int16_t left_toe = ads_left.readADC_SingleEnded(2);

  // Read right foot sensors (ADS1115 @ 0x49)
  int16_t right_heel = ads_right.readADC_SingleEnded(0);
  int16_t right_ball = ads_right.readADC_SingleEnded(1);
  int16_t right_toe = ads_right.readADC_SingleEnded(2);

  // Send via BLE at 50Hz (20ms interval)
  delay(20);
}
```

---

## Helpful Resources

### Component Datasheets
- **ESP32-WROOM-32:** https://www.espressif.com/sites/default/files/documentation/esp32-wroom-32_datasheet_en.pdf
- **ADS1115:** https://www.ti.com/lit/ds/symlink/ads1115.pdf
- **CP2102N:** https://www.silabs.com/documents/public/data-sheets/cp2102n-a01-datasheet.pdf
- **AMS1117-3.3:** https://www.advanced-monolithic.com/pdf/noch/ams1117.pdf

### Development Tools
- **KiCad:** https://www.kicad.org/
- **JLCPCB:** https://www.jlcpcb.com/
- **LCSC:** https://www.lcsc.com/
- **Arduino IDE:** https://www.arduino.cc/en/software
- **ESP32 Arduino Core:** https://github.com/espressif/arduino-esp32

### Reference Examples
- **I2C Scanner:** https://github.com/espressif/arduino-esp32/blob/master/libraries/Wire/examples/i2c_scanner/i2c_scanner.ino
- **ADS1115 Library:** https://github.com/adafruit/Adafruit_ADS1X15
- **BLE Examples:** https://github.com/espressif/arduino-esp32/tree/master/libraries/BLE

---

## Contact & Support Info

**Design Document Version:** 1.0
**Last Updated:** March 2026
**For:** Rowing/Balance Board Rehabilitation Sensor PCB v1.0

**Document Includes:**
1. PCB_DESIGN.md - Complete 50-page design document
2. NETLIST.txt - Detailed electrical connections
3. BOM.csv - Component list with part numbers
4. MANUFACTURING_ASSEMBLY.md - Step-by-step assembly guide
5. rowing-sensor.kicad_sch - KiCad schematic template
6. QUICK_REFERENCE.md - This quick reference

All files ready for manufacturing with JLCPCB or PCBWay.

---

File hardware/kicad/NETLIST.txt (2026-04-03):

# Rowing/Balance Board Rehabilitation Sensor PCB - Complete Netlist
# Format: Detailed netlist for KiCad or manual PCB routing
# Generated: March 2026

## NET DEFINITION FORMAT
# (net #NETNAME "net_name"
#   (pin REF PIN)
#   (pin REF PIN)
#   ...
# )

## POWER NETS

(net 1 "5V_USB"
  (pin U1 3)           # AMS1117 VIN input
  (pin U2 10)          # CP2102N REGIN input
  (pin C1 1)           # Input filter cap
  (pin C2 1)           # Input bulk cap
  (pin J1 5)           # USB-C VBUS pin
  (pin R1_PULLDOWN 1)  # Optional pulldown on REGIN
)

(net 2 "3V3"
  (pin U1 2)           # AMS1117 VOUT output
  (pin U3 1)           # ESP32 VCC pin 1
  (pin U3 2)           # ESP32 VCC pin 2
  (pin U4 1)           # ADS1115 #1 VDD
  (pin U5 1)           # ADS1115 #2 VDD
  (pin U2 1)           # CP2102N VCC
  (pin C3 1)           # LDO output filter
  (pin C4 1)           # LDO output bulk
  (pin C5 1)           # ESP32 decap
  (pin C6 1)           # ADS1115 #1 decap
  (pin C7 1)           # ADS1115 #2 decap
  (pin C8 1)           # CP2102N VCC decap
  (pin R10 2)          # I2C SDA pull-up
  (pin R11 2)          # I2C SCL pull-up
  (pin R12 2)          # GPIO0 pull-up (BOOT)
  (pin R13 2)          # EN pull-up (RESET)
  (pin R7 1)           # LED1 current limiting resistor
  (pin LED1 1)         # LED anode (through R7)
  (pin J8 2)           # Battery connector positive (future)
)

(net 3 "GND"
  # Ground plane net - all GND connections
  # Voltage Regulator
  (pin U1 1)           # AMS1117 GND (thermal pad)
  (pin C1 2)           # Input filter cap GND
  (pin C2 2)           # Input bulk cap GND
  (pin C3 2)           # Output filter cap GND
  (pin C4 2)           # Output bulk cap GND

  # USB Interface
  (pin J1 1)           # USB-C GND pin 1
  (pin J1 9)           # USB-C GND pin 9
  (pin U2 2)           # CP2102N GND
  (pin C8 2)           # CP2102N VCC decap GND
  (pin C9 2)           # CP2102N REGIN filter GND
  (pin R1_PULLDOWN 2)  # Optional pulldown on REGIN GND

  # ESP32
  (pin U3 15)          # ESP32 GND pin 15
  (pin U3 16)          # ESP32 GND pin 16
  (pin U3 17)          # ESP32 GND pin 17
  (pin U3 18)          # ESP32 GND pin 18
  (pin U3 19)          # ESP32 GND pin 19
  (pin U3 34)          # ESP32 GND pin 34 (shield/antenna)
  (pin C5 2)           # ESP32 decap GND

  # ADS1115 #1 (Left Foot)
  (pin U4 5)           # ADS1115 #1 GND
  (pin U4 8)           # ADS1115 #1 ADDR (tied to GND for 0x48)
  (pin U4 9)           # ADS1115 #1 A3 (unused, tied to GND)
  (pin C6 2)           # ADS1115 #1 decap GND

  # ADS1115 #2 (Right Foot)
  (pin U5 5)           # ADS1115 #2 GND
  (pin U5 9)           # ADS1115 #2 A3 (unused, tied to GND)
  (pin C7 2)           # ADS1115 #2 decap GND

  # Indicators & Controls
  (pin LED1 2)         # LED cathode
  (pin SW1 2)          # BOOT button GND side
  (pin SW2 2)          # RESET button GND side
  (pin R7 2)           # LED current limiting resistor GND side

  # FSR Sensor Connectors
  (pin J2 1)           # Left Heel FSR GND
  (pin J3 1)           # Left Ball FSR GND
  (pin J4 1)           # Left Toe FSR GND
  (pin J5 1)           # Right Heel FSR GND
  (pin J6 1)           # Right Ball FSR GND
  (pin J7 1)           # Right Toe FSR GND

  # Battery Connector
  (pin J8 1)           # Battery GND (future)

  # Pull-up resistor grounds
  (pin R10 1)          # I2C SDA pull-up to GND (other side)
  (pin R11 1)          # I2C SCL pull-up to GND (other side)
  (pin R12 1)          # GPIO0 pull-up to GND (other side)
  (pin R13 1)          # EN pull-up to GND (other side)
)

## SIGNAL NETS

# I2C Bus Nets
(net 4 "I2C_SDA"
  (pin U3 33)          # ESP32 GPIO21 (SDA)
  (pin U4 6)           # ADS1115 #1 SDA
  (pin U5 6)           # ADS1115 #2 SDA
  (pin R10 1)          # Pull-up resistor
)

(net 5 "I2C_SCL"
  (pin U3 34)          # ESP32 GPIO22 (SCL)
  (pin U4 7)           # ADS1115 #1 SCL
  (pin U5 7)           # ADS1115 #2 SCL
  (pin R11 1)          # Pull-up resistor
)

# UART Interface Nets (Programming)
(net 6 "UART_RXD"
  (pin U3 3)           # ESP32 GPIO3 (RXD/U0RXD)
  (pin U2 6)           # CP2102N RXD
  (pin R9 2)           # Series resistor
)

(net 7 "UART_TXD"
  (pin U3 1)           # ESP32 GPIO1 (TXD/U0TXD)
  (pin U2 5)           # CP2102N TXD
  (pin R8 2)           # Series resistor
)

# UART Series Resistors (for EMI/protection)
(net 8 "UART_RXD_FILTERED"
  (pin R9 1)           # GPIO3 side of resistor
  (pin U2 6)           # CP2102N RXD input
)

(net 9 "UART_TXD_FILTERED"
  (pin R8 1)           # GPIO1 side of resistor
  (pin U2 5)           # CP2102N TXD input
)

# Control Signal Nets

(net 10 "GPIO0_BOOT"
  (pin U3 27)          # ESP32 GPIO0 (BOOT pin)
  (pin SW1 1)          # BOOT button
  (pin R12 2)          # Pull-up resistor to 3V3
)

(net 11 "EN_RESET"
  (pin U3 4)           # ESP32 EN (Reset/Enable)
  (pin SW2 1)          # RESET button
  (pin R13 2)          # Pull-up resistor to 3V3
)

# USB Data Lines

(net 12 "USB_DP"
  (pin J1 7)           # USB-C D+ pin
  (pin R14 1)          # 22Ω series resistor
)

(net 13 "USB_DM"
  (pin J1 3)           # USB-C D- pin
  (pin R15 1)          # 22Ω series resistor
)

(net 14 "USB_DP_FILTERED"
  (pin R14 2)          # USB-C D+ filtered
  (pin U2 3)           # CP2102N D+ input
)

(net 15 "USB_DM_FILTERED"
  (pin R15 2)          # USB-C D- filtered
  (pin U2 4)           # CP2102N D- input
)

# FSR Sensor Input Nets (Analog)

(net 16 "FSR_LEFT_HEEL"
  (pin J2 2)           # Left Heel FSR connector signal pin
  (pin R1 2)           # Voltage divider resistor
  (pin U4 2)           # ADS1115 #1 A0 input
)

(net 17 "FSR_LEFT_BALL"
  (pin J3 2)           # Left Ball FSR connector signal pin
  (pin R2 2)           # Voltage divider resistor
  (pin U4 3)           # ADS1115 #1 A1 input
)

(net 18 "FSR_LEFT_TOE"
  (pin J4 2)           # Left Toe FSR connector signal pin
  (pin R3 2)           # Voltage divider resistor
  (pin U4 4)           # ADS1115 #1 A2 input
)

(net 19 "FSR_RIGHT_HEEL"
  (pin J5 2)           # Right Heel FSR connector signal pin
  (pin R4 2)           # Voltage divider resistor
  (pin U5 2)           # ADS1115 #2 A0 input
)

(net 20 "FSR_RIGHT_BALL"
  (pin J6 2)           # Right Ball FSR connector signal pin
  (pin R5 2)           # Voltage divider resistor
  (pin U5 3)           # ADS1115 #2 A1 input
)

(net 21 "FSR_RIGHT_TOE"
  (pin J7 2)           # Right Toe FSR connector signal pin
  (pin R6 2)           # Voltage divider resistor
  (pin U5 4)           # ADS1115 #2 A2 input
)

# Voltage Divider Reference Nets (connected to 3V3 through resistors)

(net 22 "FSR_LEFT_HEEL_REF"
  (pin 3V3)            # 3.3V supply (through R1)
  (pin R1 1)           # Voltage divider reference resistor
  (pin FSR_LEFT_HEEL)  # FSR sensor connection point
)

(net 23 "FSR_LEFT_BALL_REF"
  (pin 3V3)            # 3.3V supply (through R2)
  (pin R2 1)           # Voltage divider reference resistor
  (pin FSR_LEFT_BALL)  # FSR sensor connection point
)

(net 24 "FSR_LEFT_TOE_REF"
  (pin 3V3)            # 3.3V supply (through R3)
  (pin R3 1)           # Voltage divider reference resistor
  (pin FSR_LEFT_TOE)   # FSR sensor connection point
)

(net 25 "FSR_RIGHT_HEEL_REF"
  (pin 3V3)            # 3.3V supply (through R4)
  (pin R4 1)           # Voltage divider reference resistor
  (pin FSR_RIGHT_HEEL) # FSR sensor connection point
)

(net 26 "FSR_RIGHT_BALL_REF"
  (pin 3V3)            # 3.3V supply (through R5)
  (pin R5 1)           # Voltage divider reference resistor
  (pin FSR_RIGHT_BALL) # FSR sensor connection point
)

(net 27 "FSR_RIGHT_TOE_REF"
  (pin 3V3)            # 3.3V supply (through R6)
  (pin R6 1)           # Voltage divider reference resistor
  (pin FSR_RIGHT_TOE)  # FSR sensor connection point
)

## COMPONENT CROSS-REFERENCE

U1: AMS1117-3.3 (SOT-223) - Voltage Regulator
    3 → 5V_USB
    2 → 3V3
    1 → GND

U2: CP2102N (QFN-28) - USB-to-UART Bridge
    VCC (1) → 3V3
    GND (2) → GND
    D+ (3) → USB_DP_FILTERED
    D- (4) → USB_DM_FILTERED
    TXD (5) → UART_TXD_FILTERED
    RXD (6) → UART_RXD_FILTERED
    REGIN (10) → 5V_USB
    Remaining → See schematic

U3: ESP32-WROOM-32 (38-pin module)
    1, 2 → 3V3
    3 → UART_RXD
    4 → EN_RESET
    15-19, 34 → GND
    21 → I2C_SDA
    22 → I2C_SCL
    27 → GPIO0_BOOT

U4: ADS1115 (MSOP-10) @ 0x48 - Left Foot ADC
    1 → 3V3
    2 → FSR_LEFT_HEEL
    3 → FSR_LEFT_BALL
    4 → FSR_LEFT_TOE
    5 → GND
    6 → I2C_SDA
    7 → I2C_SCL
    8 → GND (ADDR pin)
    9 → GND (A3)
    10 → GND (DECAP)

U5: ADS1115 (MSOP-10) @ 0x49 - Right Foot ADC
    1 → 3V3
    2 → FSR_RIGHT_HEEL
    3 → FSR_RIGHT_BALL
    4 → FSR_RIGHT_TOE
    5 → GND
    6 → I2C_SDA
    7 → I2C_SCL
    8 → 3V3 (ADDR pin)
    9 → GND (A3)
    10 → GND (DECAP)

R1: 10kΩ - Left Heel FSR voltage divider
    1 → 3V3
    2 → FSR_LEFT_HEEL

R2: 10kΩ - Left Ball FSR voltage divider
    1 → 3V3
    2 → FSR_LEFT_BALL

R3: 10kΩ - Left Toe FSR voltage divider
    1 → 3V3
    2 → FSR_LEFT_TOE

R4: 10kΩ - Right Heel FSR voltage divider
    1 → 3V3
    2 → FSR_RIGHT_HEEL

R5: 10kΩ - Right Ball FSR voltage divider
    1 → 3V3
    2 → FSR_RIGHT_BALL

R6: 10kΩ - Right Toe FSR voltage divider
    1 → 3V3
    2 → FSR_RIGHT_TOE

R7: 1kΩ - LED1 current limiting resistor
    1 → 3V3
    2 → LED1_ANODE

R8: 1kΩ - GPIO1/TXD series resistor
    1 → U3 GPIO1
    2 → U2 TXD

R9: 1kΩ - GPIO3/RXD series resistor
    1 → U3 GPIO3
    2 → U2 RXD

R10: 4.7kΩ - I2C SDA pull-up
    1 → I2C_SDA
    2 → 3V3

R11: 4.7kΩ - I2C SCL pull-up
    1 → I2C_SCL
    2 → 3V3

R12: 10kΩ - GPIO0 (BOOT) pull-up
    1 → GPIO0_BOOT
    2 → 3V3

R13: 10kΩ - EN (RESET) pull-up
    1 → EN_RESET
    2 → 3V3

R14: 22Ω - USB D+ series resistor
    1 → USB_DP
    2 → USB_DP_FILTERED

R15: 22Ω - USB D- series resistor
    1 → USB_DM
    2 → USB_DM_FILTERED

C1: 100nF - USB 5V input filter
    1 → 5V_USB
    2 → GND

C2: 10µF - USB 5V input bulk
    1 → 5V_USB
    2 → GND

C3: 100nF - LDO output filter
    1 → 3V3
    2 → GND

C4: 10µF - LDO output bulk
    1 → 3V3
    2 → GND

C5: 100nF - ESP32 VCC decoupling
    1 → 3V3
    2 → GND

C6: 100nF - ADS1115 #1 decoupling
    1 → 3V3
    2 → GND

C7: 100nF - ADS1115 #2 decoupling
    1 → 3V3
    2 → GND

C8: 100nF - CP2102N VCC filter
    1 → 3V3
    2 → GND

C9: 100nF - CP2102N REGIN filter
    1 → 5V_USB
    2 → GND

C10: 100nF - BOOT button debounce (optional)
    1 → GPIO0_BOOT
    2 → GND

C11: 100nF - RESET button debounce (optional)
    1 → EN_RESET
    2 → GND

LED1: Red LED 0603
    1 (anode) → R7 pin 2 → 3V3
    2 (cathode) → GND

SW1: 6×6mm SMD Tactile - BOOT Button
    1 → GPIO0_BOOT
    2 → GND

SW2: 6×6mm SMD Tactile - RESET Button
    1 → EN_RESET
    2 → GND

J1: USB-C Connector (24-pin)
    1, 9 → GND
    3 → USB_DM
    5 → 5V_USB
    7 → USB_DP

J2: JST-PH 2-pin - Left Heel FSR
    1 → GND
    2 → FSR_LEFT_HEEL

J3: JST-PH 2-pin - Left Ball FSR
    1 → GND
    2 → FSR_LEFT_BALL

J4: JST-PH 2-pin - Left Toe FSR
    1 → GND
    2 → FSR_LEFT_TOE

J5: JST-PH 2-pin - Right Heel FSR
    1 → GND
    2 → FSR_RIGHT_HEEL

J6: JST-PH 2-pin - Right Ball FSR
    1 → GND
    2 → FSR_RIGHT_BALL

J7: JST-PH 2-pin - Right Toe FSR
    1 → GND
    2 → FSR_RIGHT_TOE

J8: JST-PH 2-pin - Battery Connector (Future)
    1 → GND
    2 → 3V3 (via future charging circuit)

## DESIGN VERIFICATION CHECKLIST

[✓] All power pins connected to 3V3
[✓] All ground pins connected to GND
[✓] I2C bus pull-ups: 4.7kΩ each on SDA and SCL
[✓] ADS1115 ADDR pins configured: U4→GND (0x48), U5→3V3 (0x49)
[✓] FSR voltage dividers: 10kΩ series resistors
[✓] USB interface: 22Ω series resistors on D+/D-
[✓] UART interface: 1kΩ series resistors on TXD/RXD
[✓] Decoupling capacitors: 100nF near each IC power pin
[✓] Bulk capacitors: 10µF for each voltage rail
[✓] ESP32 GPIO0 and EN pulled high via 10kΩ
[✓] LED circuit: Red LED with 1kΩ current limiting
[✓] Button circuits: BOOT and RESET with pull-ups

End of Netlist

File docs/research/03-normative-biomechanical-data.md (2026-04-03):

# Normative Biomechanical Reference Data for Bilateral Force-Sensing Insole Systems

*Source: Gemini Deep Research Report*
*Integrated: March 2026*

## Summary

Establishes the exact hardcodable reference baselines for healthy adults performing rowing, squat, and calf raise exercises. Covers peak force, CoP phase distribution, LSI targets, impulse baselines, and fatigue slopes.

## Peak Bilateral Ground Reaction Force

### Elite Rowing Baselines (100% capacity ceiling)

| Metric | Male | Female |
|---|---|---|
| Maximal peak force | 1350 N | 1020 N |
| Steady-state target (65%) | 877.5 N | 663.0 N |
| Per-foot target | 438.8 N | 331.5 N |

### Age-Scaled Per-Foot Targets (Biphasic Decline Model)

Pre-52 years: 0.15% decline per year from age 25 baseline
Post-52 years: 1.3% decline per year (accelerated sarcopenic decline)

Breakpoint discovered at exactly 52.0 years (362-person isokinetic study).

| Age Bracket | Sex | Max Peak (N) | Steady-State (N) | Per-Foot (N) |
|---|-----|---|---|---|
| 18-25 | Male | 1350.0 | 877.5 | 438.8 |
| 18-25 | Female | 1020.0 | 663.0 | 331.5 |
| 26-35 | Male | 1329.8 | 864.3 | 432.2 |
| 26-35 | Female | 1004.7 | 653.1 | 326.6 |
| 36-45 | Male | 1309.8 | 851.4 | 425.7 |
| 36-45 | Female | 989.4 | 643.1 | 321.6 |
| 46-60 | Male | 1194.6 | 776.5 | 388.3 |
| 46-60 | Female | 902.7 | 586.8 | 293.4 |

## Center of Pressure (CoP) Phase Distributions

### Rowing Drive Phase (3 sub-phases)

| Phase | Heel | Ball | Toe | Drive % |
|---|---|---|-----|---|
| Catch (start) | 0% | 85% | 15% | 0-15% |
| Mid-Drive | 30% | 60% | 10% | 15-60% |
| Finish | 60% | 40% | 0% | 60-100% |

### Squat Ascent (Sticking Point)

| Phase | Heel | Ball | Toe |
|---|---|---|-----|
| Ascent | 80-85% | 15-20% | <5% |

Pressure values: Heel 144-181 kPa, Forefoot 28-33 kPa during deep squat.

### Calf Raise (Peak Concentric)

| Phase | Heel | Ball | Toe |
|---|---|---|-----|
| Peak extension | 0% | 85-90% | 10-15% |

### Static Standing (Quiet)

| Condition | Hindfoot | Forefoot |
|---|---|---|
| Static | 55.6% (±18.8) | 45.2% (±19.5) |
| Dynamic | 44.1% | 55.9% (±13.4) |

### Age-Related CoP Shift
Older adults (46-60) naturally show ~5% anterior shift in resting CoP due to decreased ankle dorsiflexion ROM and increased connective tissue stiffness. Software must account for this to avoid false-positive pathological alerts.

## Limb Symmetry Index (LSI) Normative Values

### Healthy Baseline

| Metric | Value |
|---|---|
| Overall non-fatigued mean | 97.7% (SD: ±4.4%) |
| Female mean | 97.8% (SD: ±4.6%) |
| Male mean | 97.4% (SD: ±4.2%) |
| Acceptable floor (1 SD) | 93.3% |
| Hard clinical floor | 85.0% |

### Activity-Specific LSI Targets

| Activity | LSI Target | Notes |
|---|---|---|
| Rowing (steady-state) | 95.0% | Bilaterally constrained, 5-10% asymmetry under sprint |
| Squat (bilateral) | 93.0-95.0% | Slight shift to dominant leg at sticking point |
| Balance (standing) | 95.1% | Tightest: 4.9% mean difference (SD: ±3.7%) |
| General | 97.7% | Unimpaired baseline |

### Critical Finding: LSI Under Fatigue
- Healthy adults show **0% LSI degradation** under fatigue (97.7% → 98.8% — actually tightens)
- Central Governor Theory: CNS downregulates bilaterally to maintain balance
- **>5% LSI drift during session = pathological** (not normal fatigue)
- >6% asymmetric loading triggers dangerous core compensations

## Mechanical Impulse Baselines

### Per-Leg Drive Phase Impulse

| Sex | Impulse (Ns) | SD |
|-----|---|-----|
| Male | 185.3 | ±20.0 |
| Female | 136.5 | ±11.8 |

### Drive Phase Timing (1:2 drive:recovery ratio)

| Stroke Rate | Drive Time | Recovery Time | Cycle Time |
|---|---|---|---|
| 20 SPM | 1.00s | 2.00s | 3.00s |
| 24 SPM | 0.70s | 1.80s | 2.50s |

- Integration window: 0.70-1.00s for impulse calculation
- Drive time <0.60s = "rushing the slide" technique error
- Minimum sampling rate: 100 Hz (200 Hz preferred for curve fidelity)

## Neuromuscular Fatigue Slopes
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

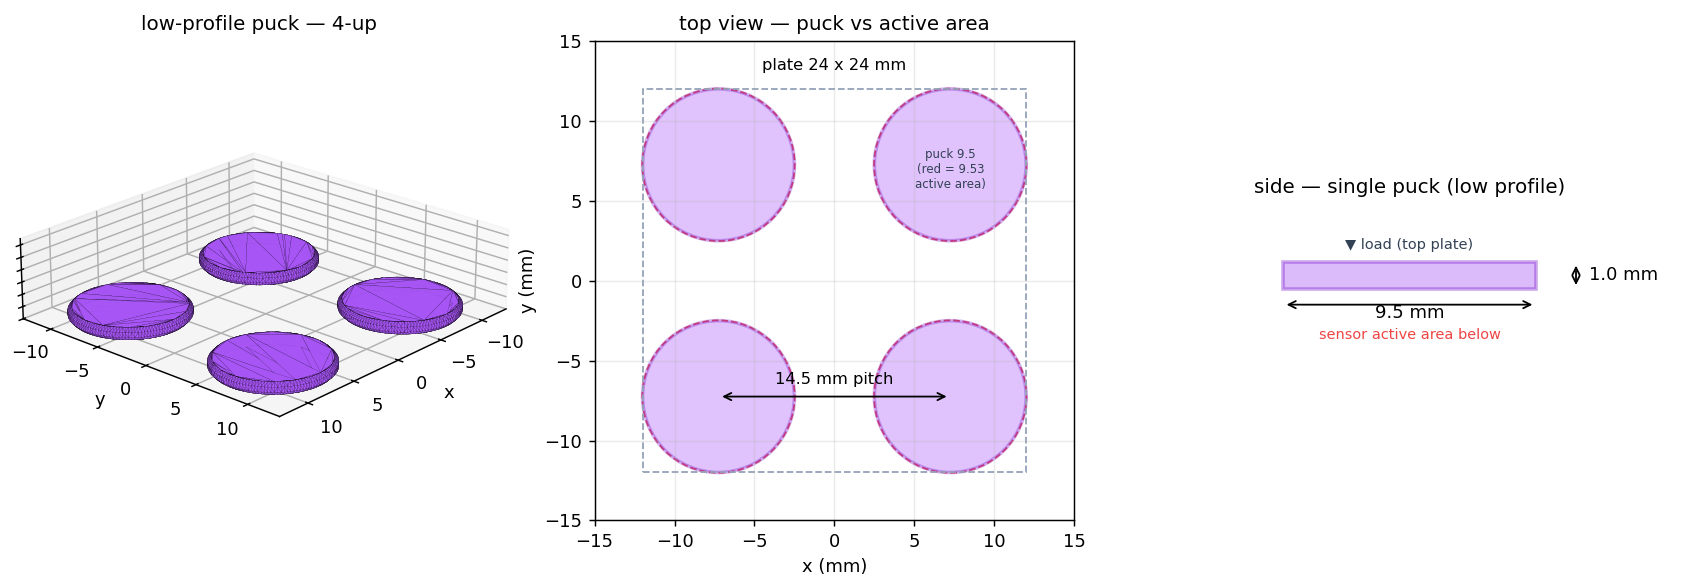
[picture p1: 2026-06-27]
hardware/flexiforce_puck/flexiforce_puck_4up_v3_render.png

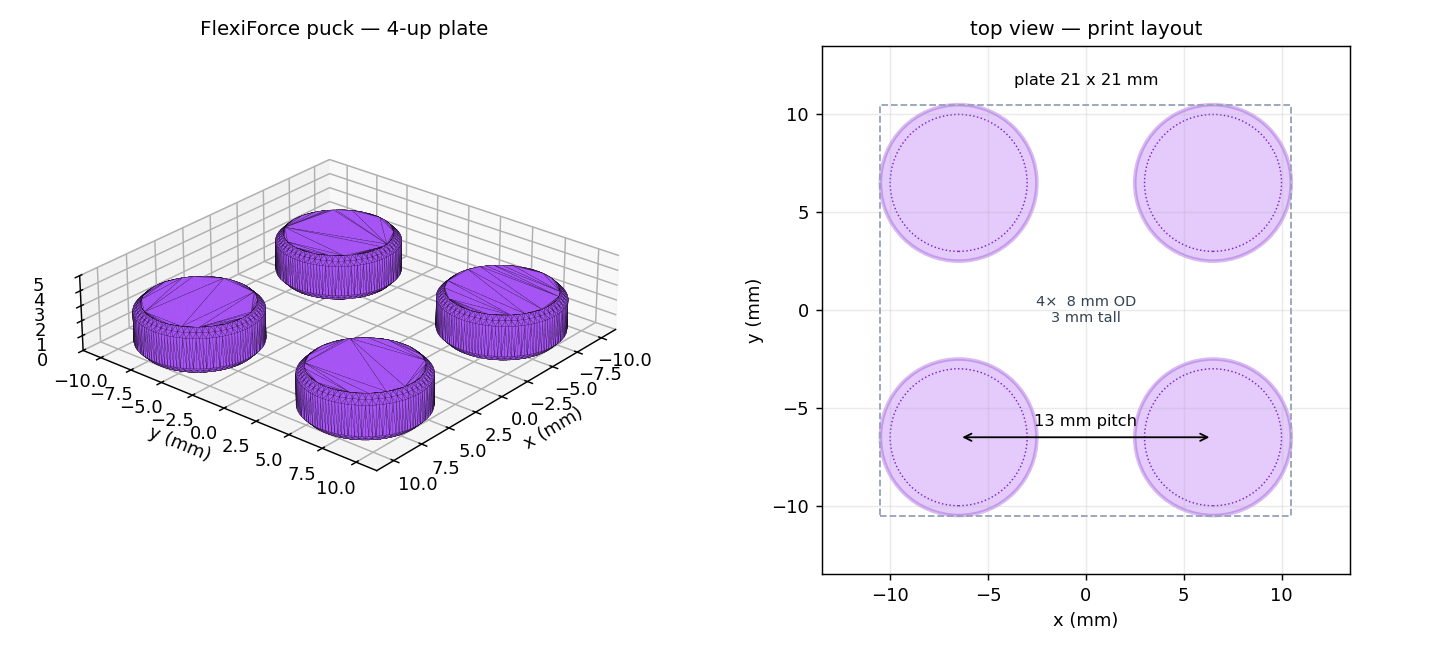
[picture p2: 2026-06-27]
hardware/flexiforce_puck/flexiforce_puck_4up_v2_render.png

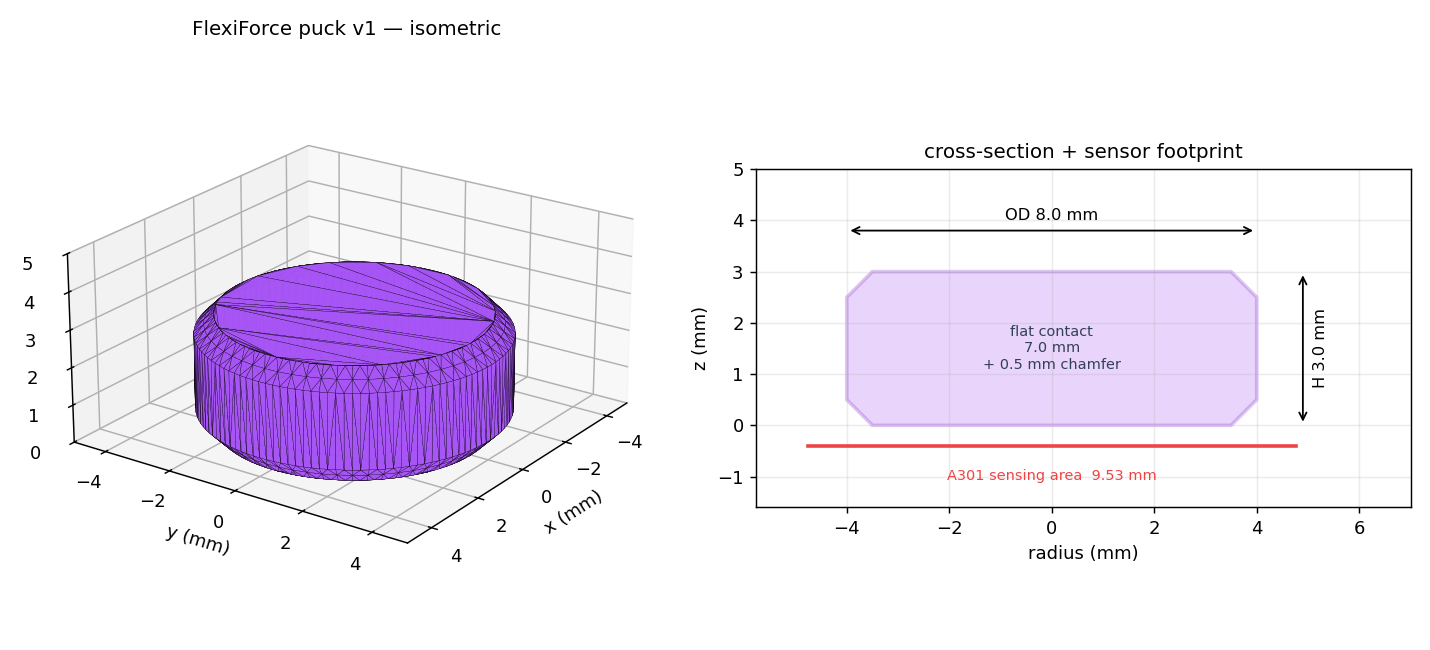
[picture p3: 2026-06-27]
hardware/flexiforce_puck/flexiforce_puck_v1_render.png

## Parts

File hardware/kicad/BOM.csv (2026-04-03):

Designator | Footprint | LCSC Part Number | JLCPCB Part Number | Quantity | Value | Description | Package | Unit Price (USD) | Total Price (USD) | Supplier | Datasheet Link
U1 | SOT-223 | C6186 | C6186 | 1 | AMS1117-3.3 | AMS1117-3.3 Voltage Regulator | SOT-223 | 0.10 | 0.10 | LCSC | https://www.advanced-monolithic.com/pdf/noch/ams1117.pdf
U2 | QFN-28 | C7520 | C7520 | 1 | CP2102N | CP2102N USB-to-UART Bridge | QFN-28 | 0.80 | 0.80 | LCSC | https://www.silabs.com/documents/public/data-sheets/cp2102n-a01-datasheet.pdf
U3 | 38-PIN_MODULE | C529143 | C529143 | 1 | ESP32-WROOM-32 | ESP32-WROOM-32 BLE/WiFi Module | 38-pin | 8.50 | 8.50 | LCSC | https://www.espressif.com/sites/default/files/documentation/esp32-wroom-32_datasheet_en.pdf
U4 | MSOP-10 | C21992 | C21992 | 1 | ADS1115 | 16-bit I2C ADC | MSOP-10 | 1.20 | 1.20 | LCSC | https://www.ti.com/lit/ds/symlink/ads1115.pdf
U5 | MSOP-10 | C21992 | C21992 | 1 | ADS1115 | 16-bit I2C ADC | MSOP-10 | 1.20 | 1.20 | LCSC | https://www.ti.com/lit/ds/symlink/ads1115.pdf
R1 | 0603 | C14663 | C14663 | 1 | 10kΩ | 10kΩ 5% 1/10W Resistor | 0603 | 0.01 | 0.01 | LCSC | N/A
R2 | 0603 | C14663 | C14663 | 1 | 10kΩ | 10kΩ 5% 1/10W Resistor | 0603 | 0.01 | 0.01 | LCSC | N/A
R3 | 0603 | C14663 | C14663 | 1 | 10kΩ | 10kΩ 5% 1/10W Resistor | 0603 | 0.01 | 0.01 | LCSC | N/A
R4 | 0603 | C14663 | C14663 | 1 | 10kΩ | 10kΩ 5% 1/10W Resistor | 0603 | 0.01 | 0.01 | LCSC | N/A
R5 | 0603 | C14663 | C14663 | 1 | 10kΩ | 10kΩ 5% 1/10W Resistor | 0603 | 0.01 | 0.01 | LCSC | N/A
R6 | 0603 | C14663 | C14663 | 1 | 10kΩ | 10kΩ 5% 1/10W Resistor | 0603 | 0.01 | 0.01 | LCSC | N/A
R7 | 0603 | C14663 | C14663 | 1 | 1kΩ | 1kΩ 5% 1/10W Resistor | 0603 | 0.01 | 0.01 | LCSC | N/A
R8 | 0603 | C14663 | C14663 | 1 | 1kΩ | 1kΩ 5% 1/10W Resistor | 0603 | 0.01 | 0.01 | LCSC | N/A
R9 | 0603 | C14663 | C14663 | 1 | 1kΩ | 1kΩ 5% 1/10W Resistor | 0603 | 0.01 | 0.01 | LCSC | N/A
R10 | 0603 | C14631 | C14631 | 1 | 4.7kΩ | 4.7kΩ 5% 1/10W Resistor | 0603 | 0.01 | 0.01 | LCSC | N/A
R11 | 0603 | C14631 | C14631 | 1 | 4.7kΩ | 4.7kΩ 5% 1/10W Resistor | 0603 | 0.01 | 0.01 | LCSC | N/A
R12 | 0603 | C14663 | C14663 | 1 | 10kΩ | 10kΩ 5% 1/10W Resistor | 0603 | 0.01 | 0.01 | LCSC | N/A
R13 | 0603 | C14663 | C14663 | 1 | 10kΩ | 10kΩ 5% 1/10W Resistor | 0603 | 0.01 | 0.01 | LCSC | N/A
R14 | 0603 | C25119 | C25119 | 1 | 22Ω | 22Ω 5% 1/10W Resistor | 0603 | 0.01 | 0.01 | LCSC | N/A
R15 | 0603 | C25119 | C25119 | 1 | 22Ω | 22Ω 5% 1/10W Resistor | 0603 | 0.01 | 0.01 | LCSC | N/A
C1 | 0603 | C14663 | C14663 | 1 | 100nF | 100nF 10% X7R Capacitor | 0603 | 0.01 | 0.01 | LCSC | N/A
C2 | 1206 | C13585 | C13585 | 1 | 10µF | 10µF 20% Electrolytic | 1206 | 0.05 | 0.05 | LCSC | N/A
C3 | 0603 | C14663 | C14663 | 1 | 100nF | 100nF 10% X7R Capacitor | 0603 | 0.01 | 0.01 | LCSC | N/A
C4 | 1206 | C13585 | C13585 | 1 | 10µF | 10µF 20% Electrolytic | 1206 | 0.05 | 0.05 | LCSC | N/A
C5 | 0603 | C14663 | C14663 | 1 | 100nF | 100nF 10% X7R Capacitor | 0603 | 0.01 | 0.01 | LCSC | N/A
C6 | 0603 | C14663 | C14663 | 1 | 100nF | 100nF 10% X7R Capacitor | 0603 | 0.01 | 0.01 | LCSC | N/A
C7 | 0603 | C14663 | C14663 | 1 | 100nF | 100nF 10% X7R Capacitor | 0603 | 0.01 | 0.01 | LCSC | N/A
C8 | 0603 | C14663 | C14663 | 1 | 100nF | 100nF 10% X7R Capacitor | 0603 | 0.01 | 0.01 | LCSC | N/A
C9 | 0603 | C14663 | C14663 | 1 | 100nF | 100nF 10% X7R Capacitor | 0603 | 0.01 | 0.01 | LCSC | N/A
C10 | 0603 | C14663 | C14663 | 1 | 100nF | 100nF 10% X7R Capacitor (Optional) | 0603 | 0.01 | 0.01 | LCSC | N/A
C11 | 0603 | C14663 | C14663 | 1 | 100nF | 100nF 10% X7R Capacitor (Optional) | 0603 | 0.01 | 0.01 | LCSC | N/A
LED1 | 0603 | C2286 | C2286 | 1 | Red LED | Red LED 0603 | 0603 | 0.05 | 0.05 | LCSC | N/A
SW1 | 6X6MM | C318884 | C318884 | 1 | 6x6mm Button | 6×6mm SMD Tactile Button | 6X6MM | 0.10 | 0.10 | LCSC | N/A
SW2 | 6X6MM | C318884 | C318884 | 1 | 6x6mm Button | 6×6mm SMD Tactile Button | 6X6MM | 0.10 | 0.10 | LCSC | N/A
J1 | USB-C-24PIN | C165948 | C165948 | 1 | USB-C Mid-Mount | USB-C Connector 24-pin Mid-Mount | USB-C SMD | 0.35 | 0.35 | LCSC | N/A
J2 | JST-PH2 | C157436 | C157436 | 1 | JST-PH 2-pin | JST-PH 2-pin Connector (SMD) | JST-PH 2PIN | 0.10 | 0.10 | LCSC | N/A
J3 | JST-PH2 | C157436 | C157436 | 1 | JST-PH 2-pin | JST-PH 2-pin Connector (SMD) | JST-PH 2PIN | 0.10 | 0.10 | LCSC | N/A
J4 | JST-PH2 | C157436 | C157436 | 1 | JST-PH 2-pin | JST-PH 2-pin Connector (SMD) | JST-PH 2PIN | 0.10 | 0.10 | LCSC | N/A
J5 | JST-PH2 | C157436 | C157436 | 1 | JST-PH 2-pin | JST-PH 2-pin Connector (SMD) | JST-PH 2PIN | 0.10 | 0.10 | LCSC | N/A
J6 | JST-PH2 | C157436 | C157436 | 1 | JST-PH 2-pin | JST-PH 2-pin Connector (SMD) | JST-PH 2PIN | 0.10 | 0.10 | LCSC | N/A
J7 | JST-PH2 | C157436 | C157436 | 1 | JST-PH 2-pin | JST-PH 2-pin Connector (SMD) | JST-PH 2PIN | 0.10 | 0.10 | LCSC | N/A
J8 | JST-PH2 | C157436 | C157436 | 1 | JST-PH 2-pin | JST-PH 2-pin Connector (SMD) - NOT POPULATED | JST-PH 2PIN | 0.10 | 0.00 | LCSC | N/A
Notes:
- ESP32-WROOM-32 part number may vary; check JLCPCB/LCSC for availability
- R7 value (1kΩ) can be adjusted based on desired LED brightness (1kΩ = ~3mA at 3.3V)
- Button debounce capacitors (C10 | C11) are optional; include if design requires hardware debouncing
- Prices shown are approximate single-unit costs; bulk pricing available
- Total estimated component cost: ~$15-20 per board (excluding PCB manufacturing)
- USB-C connector alternative: GCT USB-C Mid-Mount (part C165948 on LCSC)
- For JLCPCB PCBA service: Ensure all parts are in JLCPCB's extended library or basic library

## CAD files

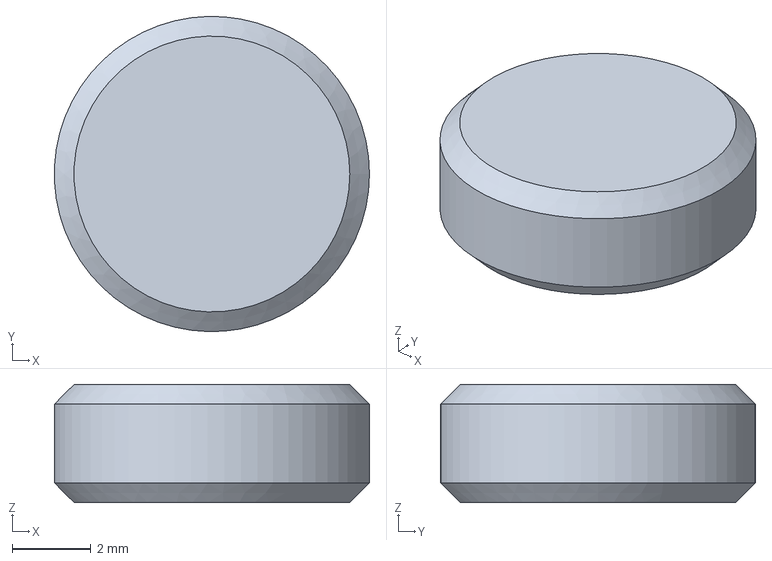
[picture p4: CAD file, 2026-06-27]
hardware/flexiforce_puck/flexiforce_puck_v1.step
7.99 x 8.00 x 3.00 mm

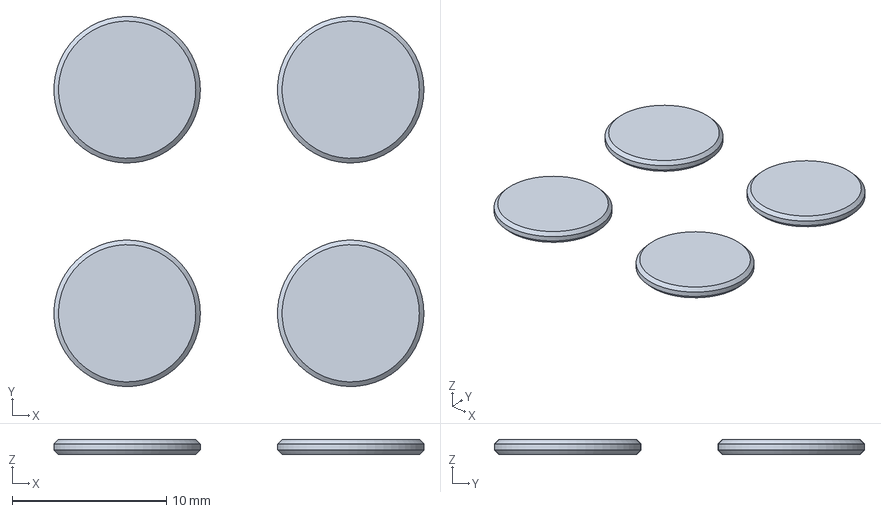
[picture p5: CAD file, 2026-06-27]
hardware/flexiforce_puck/flexiforce_puck_4up_v3.step
24.0 x 24.0 x 1.00 mm

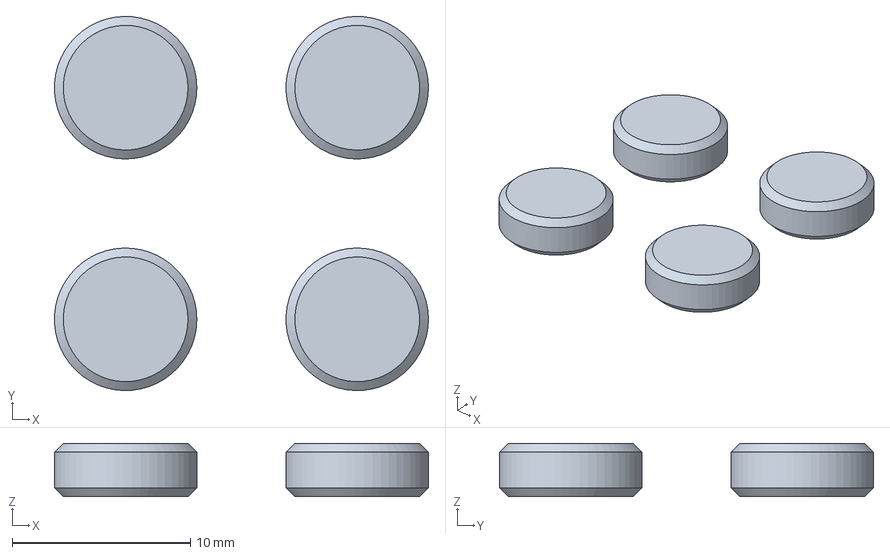
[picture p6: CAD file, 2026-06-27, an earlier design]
hardware/flexiforce_puck/flexiforce_puck_4up_v2.step
21.0 x 21.0 x 3.00 mm

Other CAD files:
hardware/flexiforce_puck/flexiforce_puck_4up_v2.stl
hardware/flexiforce_puck/flexiforce_puck_4up_v3.stl
hardware/flexiforce_puck/flexiforce_puck_v1.stl

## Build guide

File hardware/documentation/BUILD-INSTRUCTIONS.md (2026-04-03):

# Balance Board — 4-Sensor FSR Build Instructions

Quick breadboard prototype for bilateral balance assessment using an ESP32-S3-DevKitC-1 N16R8.

## What You Need

### Parts

| Item | Qty | Notes |
|---|-----|---|
| Square FSR (Adafruit 1075) | 4 | Interlink 406. Do NOT use the round ones (Adafruit 166) — they max out at 10N, useless for body weight |
| 10kΩ resistors | 4 | 1/4W through-hole |
| ESP32-S3-DevKitC-1 N16R8 | 1 | Must be the S3 variant (16MB flash, 8MB PSRAM). The board has "ESP32-S3" printed on the module and GPIO numbers silk-screened on both pin headers |
| Breadboard | 1 | Full-size (830 tie points). The DevKitC is wide — it takes up almost the entire width. You need at least 1 free row on each side for jumper access |
| Jumper wires | ~12 | Male-to-male for breadboard connections |
| USB-C cable (data-capable) | 1 | For power and serial data. Some cheap cables are charge-only and won't work |
| A board to stand on | 1 | Plywood, cutting board, anything rigid and flat, roughly 45cm x 30cm |

### Optional But Helpful

- Double-sided tape or gaffer tape (to stick FSRs to the board)
- Rubber shelf liner sheet (put on top of the FSRs — prevents foot slip and distributes force more evenly across each sensor face)
- Sharpie (to mark foot positions)
- Multimeter (for verifying wiring before power-on)

## ESP32-S3-DevKitC-1 N16R8 Pinout Reference

The board has two rows of 20 pins each running along the long edges, with the USB-C connector at one end. Hold the board with the **USB-C connector pointing toward you** (bottom). The GPIO numbers are printed on the silkscreen next to each pin.

```
                     ┌─────────────────┐
                     │    ESP32-S3     │
                     │    N16R8        │
                     │   ┌───────┐    │
                     │   │antenna│    │
                     │   └───────┘    │
     LEFT HEADER     │               │     RIGHT HEADER
     ────────────    │               │     ────────────
     3V3  ●──────────┤               ├──────────● GND
     3V3  ●──────────┤               ├──────────● TX (GPIO43)
     RST  ●──────────┤               ├──────────● RX (GPIO44)
  ► GPIO4 ●──────────┤               ├──────────● GPIO1 ◄
    GPIO5 ●──────────┤               ├──────────● GPIO2 ◄
    GPIO6 ●──────────┤               ├──────────● GPIO42
    GPIO7 ●──────────┤               ├──────────● GPIO41
   GPIO15 ●──────────┤               ├──────────● GPIO40
   GPIO16 ●──────────┤               ├──────────● GPIO39
   GPIO17 ●──────────┤               ├──────────● GPIO38
   GPIO18 ●──────────┤               ├──────────● GPIO37
    GPIO8 ●──────────┤               ├──────────● GPIO36
   GPIO19 ●──────────┤               ├──────────● GPIO35
   GPIO20 ●──────────┤               ├──────────● GPIO0
    GPIO3 ●──────────┤               ├──────────● GPIO45
   GPIO46 ●──────────┤               ├──────────● GPIO48
    GPIO9 ●──────────┤               ├──────────● GPIO47
   GPIO10 ●──────────┤               ├──────────● GPIO21
   GPIO11 ●──────────┤               ├──────────● GPIO14
   GPIO12 ●──────────┤               ├──────────● GPIO13
                     │               │
                     │   ┌───────┐   │
                     │   │USB-C  │   │
                     └───┴───────┴───┘
                      (facing you)

  ► = pins we're using for ADC
```

**The 4 pins we need for FSR readings:**

| Pin | Location on board | GPIO | ADC Channel | Sensor |
|-----|---|---|---|---|
| Right header, 4th from top | Right side | GPIO 1 | ADC1_CH0 | FL (front-left, left ball) |
| Right header, 5th from top | Right side | GPIO 2 | ADC1_CH1 | FR (front-right, right ball) |
| Left header, 15th from top | Left side | GPIO 3 | ADC1_CH2 | RL (rear-left, left heel) |
| Left header, 4th from top | Left side | GPIO 4 | ADC1_CH3 | RR (rear-right, right heel) |

**Power pins we need:**

| Pin | Location on board | Purpose |
|-----|---|---|
| 3V3 | Left header, 1st from top | 3.3V power to breadboard + rail |
| GND | Right header, 1st from top | Ground to breadboard - rail |

All GPIO numbers are printed right on the board silkscreen, so just look for the number next to each pin.

## Sensor Placement

Stand on the board naturally with feet shoulder-width apart. Mark where your heels and balls of your feet land. Place the 4 square FSRs at these positions:

```
         FRONT (toes toward this edge)
    ┌──────────────────────────────┐
    │                              │
    │    ■ FL            FR ■      │
    │   (left ball)  (right ball)  │
    │                              │
    │                              │
    │                              │
    │    ■ RL            RR ■      │
    │   (left heel)  (right heel)  │
    │                              │
    └──────────────────────────────┘
         REAR (heels toward this edge)
```

- Left pair: ~12-15cm apart front-to-rear (ball to heel of your left foot)
- Right pair: same spacing, mirrored
- Left-right spacing: ~25-30cm center-to-center (roughly shoulder width)
- Stick the FSRs to the board with tape, sensing surface facing UP

The square FSRs are about 38mm x 38mm, so they cover a decent area under each contact point. Each FSR has two legs/tabs — they're interchangeable (no polarity).

## Wiring

Each FSR gets the same simple circuit — a voltage divider with a 10kΩ pull-up to 3.3V:

```
3.3V rail ──── 10kΩ resistor ────┬──── FSR ──── GND rail
                                 │
                             ADC pin
```

The junction between the resistor and the FSR goes to an ADC input pin. That's it per sensor. Four sensors = four identical copies of this circuit.

### Step-by-Step Breadboard Wiring

**Step 1: Seat the ESP32 on the breadboard.**

Push the DevKitC-1 into the breadboard so it straddles the center channel. The board is wide — on a standard breadboard you'll have 1-2 free tie points on each side. The USB-C connector should hang off one end of the breadboard for easy cable access.

**Step 2: Power rails.**

- Run a jumper wire from the **3V3 pin** (left header, top pin) to the breadboard **+ rail** (red).
- Run a jumper wire from the **GND pin** (right header, top pin) to the breadboard **- rail** (blue).
- If your breadboard has split rails, bridge both halves.

**Step 3: Wire FSR #1 (FL — front-left, left ball).**

- Insert a 10kΩ resistor from the **+ rail** (3.3V) to an empty row on the breadboard (let's call it row A).
- The FSR has two legs/tabs. Plug one leg into **row A** (same row as the resistor). Plug the other leg into the **- rail** (GND).
- Run a jumper wire from **row A** to the **GPIO 1 pin** on the ESP32 (right header, 4th pin from top).

**Step 4: Wire FSR #2 (FR — front-right, right ball).**

- Same thing: 10kΩ from + rail to a new row B.
- FSR from row B to - rail.
- Jumper from row B to **GPIO 2** (right header, 5th pin from top).

**Step 5: Wire FSR #3 (RL — rear-left, left heel).**

- 10kΩ from + rail to row C.
- FSR from row C to - rail.
- Jumper from row C to **GPIO 3** (left header, 15th pin from top — count down from 3V3).

**Step 6: Wire FSR #4 (RR — rear-right, right heel).**

- 10kΩ from + rail to row D.
- FSR from row D to - rail.
- Jumper from row D to **GPIO 4** (left header, 4th pin from top).

**Step 7: Double-check before plugging in USB.**

- No shorts between + and - rails (multimeter continuity mode between 3V3 and GND — should beep = BAD, should NOT beep = GOOD).
- Each FSR has one leg at the resistor junction and one leg at GND.
- Each jumper goes to the junction row, NOT directly to 3.3V or GND.
- Total connections: 2 power wires + 4 resistors + 4 FSRs + 4 ADC jumpers = 14 connections. That's it.

### Wiring Diagram (Breadboard View)

```
    + RAIL (3.3V) ─────────────────────────────────────────────
    │         │         │         │
   [10kΩ]   [10kΩ]   [10kΩ]   [10kΩ]
    │         │         │         │
    ├──FSR──  ├──FSR──  ├──FSR──  ├──FSR──
    │    │    │    │    │    │    │    │
    │    │    │    │    │    │    │    │
    │   GND   │   GND   │   GND   │   GND
    │         │         │         │
   GPIO1    GPIO2    GPIO3    GPIO4
   (FL)     (FR)     (RL)     (RR)

    - RAIL (GND) ──────────────────────────────────────────────
```

## Quick Test (No Firmware Needed)

Before even flashing firmware, verify the wiring with a multimeter:

1. Plug in the ESP32 via USB-C. The onboard power LED should light up.
2. Set multimeter to DC voltage.
3. Probe the junction point (the breadboard row where resistor meets FSR) relative to GND.
4. **With no pressure on the FSR:** should read close to **0V** (FSR resistance is very high, almost all voltage drops across the FSR, so the junction is pulled near ground).
5. **Press the FSR firmly with your thumb:** voltage should rise toward **2-3V** (FSR resistance drops, voltage divider shifts toward 3.3V).

If voltage goes UP when you press, wiring is correct. If it doesn't change or reads 3.3V constantly, the FSR isn't in the circuit (check connections). If it reads 0V always, the FSR legs might both be in the same rail.

## Flash Firmware

See `firmware/balance_board.ino`. Flash via Arduino IDE 2.x:

1. **Install ESP32 board package:** In Arduino IDE, go to File → Preferences → Additional Board Manager URLs, add: `https://raw.githubusercontent.com/espressif/arduino-esp32/gh-pages/package_esp32_index.json`. Then Tools → Board Manager → search "esp32" → install "esp32 by Espressif Systems".
2. **Select board:** Tools → Board → ESP32S3 Dev Module.
3. **Board settings:**
   - USB CDC On Boot: **Enabled**
   - USB Mode: **Hardware CDC and JTAG**
   - Flash Size: **16MB**
   - PSRAM: **OPI PSRAM**
   - Partition Scheme: **Default 4MB with spiffs** (or any scheme that fits)
4. **Select port:** Tools → Port → select the COM port that appeared when you plugged in the board. On Mac it looks like `/dev/cu.usbmodemXXXX`, on Windows `COM3` or similar, on Linux `/dev/ttyACM0`.
5. **Upload.** If it fails, hold the **BOOT button** on the DevKitC while clicking Upload, then release BOOT after "Connecting..." appears.
6. **Open Serial Monitor** at **115200 baud**. You should see the startup banner and baseline capture.

## Using It

Stand on the board with one foot on the left pair of sensors, one foot on the right pair. The firmware outputs at 20 Hz:

- Raw force values for all 4 sensors (FL, FR, RL, RR)
- Left vs right weight distribution (percentage)
- Anterior-posterior shift per foot (-1.0 = all heel, +1.0 = all ball, 0.0 = even)
- ASCII balance bar showing real-time left/right weight shift

### Data Logging

To record a session to CSV for later analysis:

```
pip install pyserial
python firmware/balance_logger.py --log my_session.csv
```

### Achilles Rehab Use

Do single-leg stance tests: stand on the injured side only and watch the anterior-posterior shift (front vs rear sensor). Compare to the healthy side. A healthy stance shows smooth, small oscillations around center. An Achilles-compensating stance often shows the weight biased toward the ball (avoiding heel load) with larger A/P oscillations.

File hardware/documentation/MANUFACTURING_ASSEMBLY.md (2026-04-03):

# Manufacturing & Assembly Guide
## Rowing/Balance Board Rehabilitation Sensor PCB

---

## Section 1: Pre-Manufacturing Preparation

### Design Files Required for Manufacturing

Before ordering your PCB, ensure you have all required Gerber files exported from KiCad:

**Essential Gerber Files:**
```
rowing-sensor-F.Cu          (Top copper layer)
rowing-sensor-B.Cu          (Bottom copper layer)
rowing-sensor-F.Mask        (Top solder mask)
rowing-sensor-B.Mask        (Bottom solder mask)
rowing-sensor-F.SilkS       (Top silkscreen)
rowing-sensor-B.SilkS       (Bottom silkscreen)
rowing-sensor-Edge.Cuts     (Board outline/dimensions)
rowing-sensor.drl           (Drill file for PTH and vias)
```

**Export Settings for KiCad:**

1. Go to: File → Plot
2. Select Plot Format: **Gerber**
3. **Gerber Options:**
   - Plot pad and via holes
   - Plot footprint references: YES
   - Plot footprint values: NO
   - Subtract soldermask from silkscreen: YES
4. **Included Layers:**
   - Front copper (F.Cu)
   - Back copper (B.Cu)
   - Front silkscreen (F.SilkS)
   - Back silkscreen (B.SilkS)
   - Front mask (F.Mask)
   - Back mask (B.Mask)
   - Edge cuts (Edge.Cuts)
5. Click "Plot All"
6. Then go to: File → Fabrication Outputs → Drill File
   - Format: Excellon
   - Mirror Y-axis: NO
   - Generate map file: YES

**Create ZIP file containing all Gerber files:**
- Create folder: `rowing-sensor_gerbers`
- Copy all .gbr files
- Copy .drl file
- ZIP entire folder
- File should be < 5MB

### Pre-Manufacturing Checklist

- [ ] All Gerber files generated and verified
- [ ] Design rule check (DRC) passed with no errors
- [ ] Board dimensions verified: 50mm × 70mm
- [ ] No isolated copper (floating traces)
- [ ] All signal integrity requirements met
- [ ] Via size and spacing correct (0.3mm dia minimum)
- [ ] Trace width/spacing correct per manufacturer specs
- [ ] Copper thickness adequate (1oz standard)
- [ ] Layer stackup verified (2-layer)
- [ ] 3D preview reviewed in KiCad
- [ ] Fab notes added to silkscreen or design notes
- [ ] BOM checked and parts available
- [ ] Quote obtained from manufacturer
- [ ] Budget approved and order ready to submit

---

## Section 2: Manufacturing via JLCPCB

### Step-by-Step JLCPCB Ordering Process

#### Step 1: Prepare Files
1. Create a folder named `rowing-sensor_gerbers`
2. Place all Gerber files (.gbr extension) in folder
3. Place drill file (.drl) in folder
4. ZIP the folder: `rowing-sensor_gerbers.zip`
5. File size should be under 5MB

#### Step 2: Navigate to JLCPCB Website
1. Go to: https://www.jlcpcb.com/
2. Click "Quote Now" or "Order Now"

#### Step 3: Upload Gerber File
1. Click "Add Gerber File"
2. Select your ZIP file
3. JLCPCB automatically detects board dimensions and layer count
4. Wait for processing (typically < 1 minute)

#### Step 4: Select Board Options

**PCB Specifications:**
- Dimension: 50 × 70 mm ✓ (auto-detected)
- Quantity: Start with 5 boards (minimum for good pricing)
- Layers: 2 layers ✓
- Material: FR-4 TG130-140
- Thickness: 1.6mm (standard)
- Min Track/Spacing: 0.2mm / 0.15mm
- Min Via: 0.3mm
- Copper Weight: 1 oz (standard)
- Surface Finish: **HASL (lead-free)** or ENIG for better solderability
- Silkscreen: White
- Gold fingers: No
- Castellated holes: No
- Flying probe test: No

**Cost Estimate:**
- 5 boards (2-layer, 50×70mm): $2-5 total
- Rush shipping (24-hour): +$10 (optional)
- Standard shipping (7-15 days): FREE
- DHL Shipping: ~$15-20

#### Step 5: Review & Place Order
1. Review all settings one more time
2. Verify board preview matches your design
3. Accept terms and conditions
4. Place order with credit card/PayPal
5. Save order number for tracking

#### Step 6: Manufacturing Timeline
- **After order:** JLCPCB confirms file processing
- **Day 1-2:** PCB fabrication
- **Day 2-3:** Quality inspection
- **Day 3+:** Shipping (varies by method)

---

## Section 3: Component Sourcing

### Option A: JLCPCB Full PCBA Service

If you want JLCPCB to assemble the PCB (easier for beginners):

#### Uploading BOM for Assembly

1. Prepare BOM in CSV format (included as BOM.csv)
2. Prepare CPL (component placement) file
3. Return to JLCPCB and click "Add Assembly"
4. Select assembly service:
   - **Standard Assembly:** All SMD components
   - **Surcharge:** 50% of board cost for first 5 units
5. Upload files:
   - BOM.csv
   - rowing-sensor.cpl (coordinate placement file)

#### BOM Format Requirements
```csv
Designator,Quantity,Footprint,LCSC Part Number,Value
U1,1,SOT-223,C6186,AMS1117-3.3
U2,1,QFN-28,C7520,CP2102N
... etc
```

#### CPL (Coordinate Placement File) Format
```csv
Designator,Mid X (mm),Mid Y (mm),Rotation (degrees),Layer
U1,10.5,20.3,0,top
U2,15.2,18.9,90,top
... etc
```

**Cost Estimate for Full Assembly:**
- PCB (5 units): $2-5
- Assembly surcharge: ~$5-10
- Components from LCSC: ~$75-100
- **Total per board with assembly: $20-40**

### Option B: Manual Assembly (Recommended for Prototype)

**Advantages:**
- Full control over component selection
- Can substitute parts if needed
- Better for learning and debugging
- More cost-effective for 1-2 units

#### Component Sourcing Strategy

1. **Primary Supplier:** LCSC (lcsc.com)
   - Owned by JLCPCB
   - Same warehouse, faster delivery
   - All parts in BOM available with LCSC part numbers
   - Competitive pricing

2. **Backup Suppliers:**
   - Digi-Key (digikey.com) - worldwide, fast shipping
   - Mouser (mouser.com) - extensive inventory
   - Amazon (for common components only)

#### Ordering from LCSC

1. Go to: https://www.lcsc.com/
2. For each component, search by LCSC part number
3. Add to cart
4. Total estimated cost: $12-18 per board (components only)
5. Shipping: 10-20 days to most countries
6. Free shipping over $50 USD

#### Ordering from Digi-Key (US/International)

1. Go to: https://www.digikey.com/
2. Search by part number or description
3. Components may be more expensive than LCSC
4. Domestic US shipping: 2-5 days
5. International: 5-14 days

### Stock Level Verification

Before ordering, verify component availability:

**Critical components to check:**
- ESP32-WROOM-32 (often backordered): ~2 week lead time
- CP2102N: Usually available
- ADS1115: Usually available
- Passive components: No issues

**Alternative parts if unavailable:**
- ESP32-WROOM-32 → ESP32-WROOM-32E (higher temp version, pin compatible)
- CP2102N → CH340C (same functionality, may need different footprint)
- ADS1115 → ADS1015 (lower resolution, pin compatible)

---

## Section 4: Hand Assembly Instructions

### Required Tools & Materials

**Soldering Equipment:**
- Soldering iron (60W recommended) or hot air rework station
- Solder paste (lead-free Sn/Ag/Cu alloy, leaded 63/37 acceptable)
- Flux pen (water-soluble paste flux recommended)
- Tweezers (fine-tipped, preferably ESD safe)
- Solder wick or desoldering pump (for corrections)
- Helping hands (PCB holder/third hand tool)

**Cleaning & Inspection:**
- Isopropyl alcohol (IPA) 99% purity
- Cotton swabs or soft brush
- Magnifying glass or jeweler's loupe (10x magnification)
- Lint-free wipes

**Testing & Verification:**
- Digital multimeter (basic features sufficient)
- USB-to-UART adapter (for UART testing, optional)
- Power supply (5V, 1A capable)
- Micro-USB cable

**Safety Equipment:**
- ESD wrist strap
- Safety glasses
- Soldering fume extractor or open window
- Wet sponge or brass wool for iron cleaning

### Pre-Assembly Setup

1. **Workspace Preparation:**
   - Clean work surface with IPA
   - Anti-static mat recommended
   - Good lighting (desk lamp + overhead light)
   - Temperature: 20-25°C for optimal soldering
   - Humidity: 40-60% (avoid dry conditions)

2. **Component Preparation:**
   - Lay out all components on clean surface
   - Organize by reference designator
   - Verify against BOM
   - Check for visible damage
   - Store IC chips in anti-static bag until needed

3. **PCB Preparation:**
   - Clean board with IPA and lint-free wipe
   - Dry completely with compressed air if available
   - Inspect for manufacturing defects
   - Verify no solder bridges from manufacturing

4. **Soldering Iron Calibration:**
   - Preheat iron to 350-380°C (iron tip should glow slightly)
   - Test on scrap solder - should melt quickly
   - Wipe on damp sponge or brass wool before each joint

### Detailed Assembly Steps

#### Phase 1: Apply Solder Paste

**Option A: Using Solder Paste & Reflow**

1. Print or create a solder paste stencil (optional but recommended)
2. Place stencil over PCB, align with fiducial marks if available
3. Apply solder paste with squeegee:
   - At 45° angle
   - Single stroke across board
   - Even pressure (don't press hard)
4. Remove stencil carefully
5. Verify paste coverage:
   - Each pad should have paste
   - Paste should not bridge pads
   - Paste height: 0.1-0.15mm

**Option B: Manual Paste Application**

1. Use solder paste with syringe applicator
2. Apply small dot to each pad:
   - Volume: match pad size (typically 0.1-0.3mm)
   - Too much → bridges; Too little → cold solder
3. Use flux pen to spread paste if needed

#### Phase 2: Reflow Soldering Process

**If using reflow oven (preferred):**

1. Set oven profile:
   - Preheat: 100-150°C for 2-3 min
   - Thermal soak: 150-200°C for 1-2 min
   - Reflow peak: 240-260°C for 10-30 seconds
   - Cool: Natural cooling to <100°C

2. Place assembled board in oven
3. Monitor temperature curve
4. Remove board when cool enough to touch (~60°C)

**If using hot air station (manual method):**

1. Set air flow to medium (~15-20% power)
2. Set temperature to 350°C
3. Hover over each component area:
   - Keep distance: 2-3cm
   - Duration: 5-10 seconds per chip
   - Watch for solder to become shiny (liquid)
   - Move away when solder wets pads
4. Allow board to cool naturally

**If using soldering iron (time-consuming but works):**

1. For each component:
   - Heat both pads simultaneously (iron tip touching both)
   - Apply solder to joint (not iron)
   - Remove iron once solder flows
   - Duration: 2-3 seconds per joint
2. Start with passive components (resistors, capacitors)
3. Then ICs and modules

#### Phase 3: Component Placement Sequence

**For Reflow Method (paste + components):**

1. **Passives First:**
   - R1-R15 (resistors) - smallest, first to place
   - C1-C11 (capacitors) - slightly larger
   - Verify orientation (resistors/caps have no polarity)

2. **ICs (Medium complexity):**
   - U4, U5 (ADS1115 MSOP-10) - 10 pins, easier
   - U2 (CP2102N QFN-28) - 28 pins, requires care
   - U1 (AMS1117 SOT-223) - 3 pins, simple

3. **Large Modules (Last):**
   - U3 (ESP32-WROOM-32) - 38 pins, most critical
   - Place carefully, ensure good contact

4. **Connectors & Discrete:**
   - J1 (USB-C) - must be aligned perfectly
   - J2-J8 (JST connectors) - straightforward
   - LED1 (check polarity: long leg = anode = 3V3)
   - SW1, SW2 (buttons) - no polarity

#### Phase 4: Verification (Post-Reflow)

1. **Visual Inspection:**
   - Examine each solder joint with magnification
   - Look for:
     - Shiny appearance (good) vs dull (cold solder)
     - No bridges between pads
     - All pads have solder coverage
     - No missing components

2. **Repair Cold Solder Joints:**
   - Add a small amount of flux
   - Reflow with iron at 350°C
   - Touch iron to joint for 1-2 seconds
   - Add tiny amount of solder if needed

3. **Remove Bridges:**
   - Use desoldering wick:
     - Place wick on bridge
     - Heat with iron (2-3 seconds)
     - Remove wick + solder
   - Or use solder pump to suck up excess solder

### Hand Soldering Details (If No Reflow Oven)

#### Soldering Resistors (R1-R15)

1. Place resistor on PCB (no polarity)
2. Bend legs slightly to hold in place
3. Heat both pads with iron tip:
   - Tip should contact both pads simultaneously
   - Temperature: 350-380°C
   - Duration: 2-3 seconds
4. Apply solder to joint (not iron):
   - Just a small amount needed
   - Solder should flow between pad and leg
5. Remove iron and let cool

**Correct joint:** Shiny, cone-shaped, smooth
**Wrong joints:**
- Cold solder: Dull, grainy appearance
- Too much solder: Large blob, risk of bridges
- Insufficient heat: Solder doesn't flow

#### Soldering Capacitors (C1-C11)

1. Place capacitor on PCB (verify polarity if electrolytic)
   - For electrolytic: longer leg = positive, stripe = negative
   - For ceramic/film: no polarity concerns
2. Bend legs slightly to hold in place
3. Solder both ends with iron (same as resistors)
4. Verify solder coverage on both pads

#### Soldering ICs (U1, U2, U4, U5)

**For SOT-223 (U1 - AMS1117):**
1. Place IC on PCB (verify orientation - lettering should be readable)
2. Start with one pin:
   - Heat pad + IC pin with iron
   - Apply tiny solder ball
   - Let cool
3. Then solder remaining 2 pins normally
4. Verify no bridges between pins

**For MSOP-10 (U4, U5 - ADS1115):**
1. Place IC on PCB (use magnification to verify alignment)
2. Solder one corner pin first to hold in place
3. Solder remaining pins one by one:
   - Heat pad + IC pin for 1-2 seconds
   - Apply solder to joint
   - Move to next pin
4. Check for bridges between pins (common with MSOP packages)
5. Use desoldering wick to remove any bridges

**For QFN-28 (U2 - CP2102N):**
1. This is trickiest - use extra care
2. Place IC with alignment verification
3. Solder one corner pin to hold
4. Solder all visible perimeter pins
5. Check alignment before soldering center pins
6. Use flux to help solder flow between pads
7. Inspect thoroughly for bridges

#### Soldering ESP32 Module (U3)

1. This is the most critical component
2. Verify antenna area clearance
3. Align module carefully with pads
4. Solder corner pins first (6 corner pads):
   - Pin 1, 38, 15, 22 (approximate corners)
5. Solder remaining pins methodically
6. Use magnification to verify alignment as you go
7. Final check: all pins soldered, no bridges

#### Soldering Connectors (J1-J8)

**USB-C Connector (J1):**
1. Most critical connector for power and programming
2. Alignment is crucial - use multiple passes if needed
3. Solder GND tabs first (pins 1, 9)
4. Then solder data pins (D+, D-)
5. Finally VBUS (power pin 5)
6. Verify with multimeter:
   - VBUS to GND: should show short when powered
   - D+ to D-: should be open (not shorted)

**JST-PH Connectors (J2-J8):**
1. Standard 2-pin connector
2. Simple to solder (only 2 pins each)
3. Verify orientation: pin 1 should align with marking

#### Soldering LEDs & Buttons

**Red LED (LED1):**
1. Polarity is critical:
   - Long leg (anode) → connects to 3V3 (through R7)
   - Short leg (cathode) → connects to GND
2. After soldering, test with 3.3V (should glow dimly)

**Buttons (SW1, SW2):**
1. No polarity - can be soldered either way
2. Verify they press smoothly
3. Test with multimeter after soldering:
   - Should show low resistance when pressed
   - Should show high resistance when released

---

## Section 5: Quality Control & Testing

### Electrical Testing (Before Power-On)

#### Continuity Testing

With power OFF, use digital multimeter in continuity mode:

**Test 1: Check for shorts**
```
Connection                    Expected Result
5V_USB to GND                High impedance (beep = BAD)
3V3 to GND                   High impedance (beep = BAD)
SDA to GND                   ~4.7kΩ (pull-up resistor)
SCL to GND                   ~4.7kΩ (pull-up resistor)
```

**Test 2: Verify power traces**
```
Connection                    Expected Result
USB connector pin 5 to U1     Should show ~0Ω (direct trace)
U1 output (pin 2) to 3V3      Should show ~0Ω
3V3 to U3 VCC pins            Should show ~0Ω
GND connections               All should be ~0Ω (solid ground plane)
```

#### Visual Inspection Checklist

After assembly, examine board carefully:

- [ ] All solder joints are shiny and smooth (not dull)
- [ ] No visible bridges between pads
- [ ] No cold solder joints (grainy appearance)
- [ ] All components are flush against board
- [ ] No lifted component legs
- [ ] USB connector is properly aligned
- [ ] Buttons move freely
- [ ] LED is in correct orientation
- [ ] No flux residue on board (or residue is clean)
- [ ] PCB has no physical damage

### Initial Power-On Testing

**WARNING: Use external 5V power supply, NOT computer USB initially**

#### Power-On Sequence

1. **Prepare power supply:**
   - Set to 5V output
   - Current limit to 500mA (protects against shorts)
   - Keep ready to disable if anything goes wrong

2. **First power attempt (very brief):**
   - Connect power supply negative (black) to PCB GND
   - Connect power supply positive (red) to PCB 5V_USB
   - Look for LED1 illumination
   - Check for unusual warmth or smoke
   - Duration: 2-3 seconds maximum

3. **If all OK, continue to full power:**
   - Keep powered for 30 seconds
   - Check U1 (AMS1117) for warmth (should be slightly warm, not hot)
   - If getting hot: disconnect power, check for shorts
   - Measure voltage:
     - 5V_USB: should read 5.0V ±0.5V
     - 3V3: should read 3.3V ±0.1V

4. **If any problems:**
   - Disconnect immediately
   - Use multimeter to check for shorts
   - Visually inspect solder joints
   - Look for solder bridges or lifted components
   - Repair issues before retry

#### Detailed Voltage Measurements

Once power is verified stable:

**Test point measurements with 5V external power applied:**

| Test Point | Expected Voltage | Tolerance | Notes |
|---|---|---|---|
| 5V_USB rail | 5.0V | ±0.5V | USB input rail |
| 3V3 rail | 3.3V | ±0.1V | Main logic power |
| U1 GND pin | 0.0V | ±0.05V | Reference |
| U3 GND pins | 0.0V | ±0.05V | Reference |
| GPIO0 pin | 3.3V | ±0.2V | Should read high (pulled up) |
| EN pin | 3.3V | ±0.2V | Should read high (pulled up) |
| I2C SDA | 3.3V | ±0.2V | Should read high (pulled up) |
| I2C SCL | 3.3V | ±0.2V | Should read high (pulled up) |

### I2C Bus Communication Test

#### Required: I2C Scanner Firmware

Once powered successfully:

1. **Connect USB:**
   - Connect USB-C cable from PCB to computer
   - CP2102N should be recognized as USB serial device
   - Windows: May need driver (see below)
   - Mac/Linux: Usually automatic

2. **Windows Driver Installation (if needed):**
   - Download from: https://www.silabs.com/developers/usb-to-uart-bridge-vcp-drivers
   - Install CP210x Universal Windows Driver
   - Restart computer
   - Device should appear as "COM" port

3. **Flash I2C Scanner Firmware:**
   - Use Arduino IDE or ESP-IDF
   - Code available at: https://github.com/espressif/arduino-esp32/blob/master/libraries/Wire/examples/i2c_scanner/i2c_scanner.ino
   - Flash with BOOT + RESET button sequence:
     1. Hold BOOT button (SW1)
     2. Press RESET button (SW2)
     3. Release RESET button
     4. Release BOOT button
     5. ESP32 should now be in bootloader mode
   - Select COM port and flash

4. **Run I2C Scanner:**
   - Open serial monitor (115200 baud)
   - ESP32 will scan I2C bus and report addresses
   - Expected output:
     ```
     i2c scanner
     Scanning...
     I2C device found at address 0x48 (ADS1115 #1)
     I2C device found at address 0x49 (ADS1115 #2)
     Done
     ```

#### Troubleshooting I2C Issues

| Issue | Cause | Solution |
|---|---|---|
| No I2C devices found | SDA/SCL lines shorted | Check for solder bridges on I2C lines |
| No I2C devices found | Pull-ups missing | Verify R10, R11 are 4.7kΩ and connected |
| Partial scan result | One ADS chip not responding | Check ADDR pin connections (R4 to GND, R5 to 3V3) |
| I2C bus is stuck low | Component pin shorted | Carefully inspect ADS ICs for cold solder |
| Serial monitor shows garbage | Wrong baud rate | Verify 115200 baud rate |
| No serial port visible | CP2102N not recognized | Install CP210x drivers, check USB cable |

### Analog Input Testing

#### Test without FSR sensors

1. **Power the board with USB**
2. **Create test sketch** to read ADS1115 values:
   ```cpp
   #include <Wire.h>
   #include <Adafruit_ADS1X15.h>

   Adafruit_ADS1115 ads1(0x48);
   Adafruit_ADS1115 ads2(0x49);

   void setup() {
     Serial.begin(115200);
     ads1.begin();
     ads2.begin();
   }

   void loop() {
     int16_t adc0 = ads1.readADC_SingleEnded(0);
     int16_t adc1 = ads1.readADC_SingleEnded(1);
     int16_t adc2 = ads1.readADC_SingleEnded(2);
     int16_t adc3 = ads2.readADC_SingleEnded(0);
     int16_t adc4 = ads2.readADC_SingleEnded(1);
     int16_t adc5 = ads2.readADC_SingleEnded(2);

     Serial.print("LH:");Serial.print(adc0);Serial.print(" LB:");Serial.print(adc1);
     Serial.print(" LT:");Serial.print(adc2);Serial.print(" RH:");Serial.print(adc3);
     Serial.print(" RB:");Serial.print(adc4);Serial.print(" RT:");Serial.println(adc5);
     delay(50);  // 50ms = 20Hz sampling
   }
   ```

3. **Test each channel:**
   - With nothing connected: should read ~0
   - Jumper pin 2 of connector to 3V3: should read maximum (~32767)
   - Jumper pin 2 of connector to GND: should read 0
   - Cycle through all 6 channels (J2-J7)

### System-Level Testing

#### Memory & Performance

1. **ESP32 Startup Test:**
   - Power board via USB
   - Serial monitor should show startup messages:
     ```
     ets Jun  8 2016 00:22:57

     rst:0x1 (POWERON_RESET),boot:0x13 (SPI_FAST_BOOT)
     ...
     Ready!
     ```

2. **Free Memory Check:**
   - Add to firmware:
     ```cpp
     Serial.print("Free heap: ");
     Serial.println(ESP.getFreeHeap());
     ```
   - Should show > 100KB free heap
   - Should remain stable (not decreasing)

3. **I2C Communication Reliability:**
   - Run continuous I2C reads for 1 hour
   - Should see no errors or timeouts
   - All sensor values should be responsive

#### BLE Communication Test

1. **Flash BLE advertising firmware**
2. **Scan with phone BLE app:**
   - Download "nRF Connect" or "BLE Scanner" app
   - Should see device advertising
   - RSSI should be reasonable (-50 to -70 dBm typical)

3. **Connect and test:**
   - Connect to device
   - Should see services and characteristics
   - Verify data streaming

---

## Section 6: Troubleshooting Guide

### Common Assembly Problems & Solutions

#### Problem: Solder bridges between pads

**Symptoms:** I2C devices not responding, power issues

**Cause:** Excess solder, poor solder paste application

**Solutions:**
1. Inspect with magnification
2. Use desoldering wick:
   - Wet wick in flux
   - Place on bridge
   - Heat with iron (2 seconds)
   - Remove wick with solder
3. If bridge is between IC pins:
   - Add flux to bridge
   - Use fine iron tip
   - Carefully melt solder and let flow away
4. Re-test with multimeter

#### Problem: Cold solder joint (dull appearance)

**Symptoms:** Intermittent connections, random I2C errors

**Cause:** Insufficient heat or not enough solder

**Solutions:**
1. Apply more flux to joint
2. Reheat with clean iron
3. Add small amount of solder
4. Let cool completely
5. Re-test

#### Problem: USB connector not recognized by computer

**Symptoms:** No COM port appears, USB shows "Unknown Device"

**Cause:**
- D+ or D- line not properly soldered
- CP2102N not powered
- Solder bridge on USB lines

**Solutions:**
1. Check continuity:
   - USB pin 5 → U2 REGIN (should be 0Ω)
   - USB pin 3 (D-) → 22Ω resistor → U2 pin 4
   - USB pin 7 (D+) → 22Ω resistor → U2 pin 3
2. Measure U2 VCC: should read 3.3V
3. Check for bridges between D+/D- and power
4. Reinstall CP2102N driver on computer
5. Try different USB cable

#### Problem: I2C devices not responding (0x48 and 0x49 not found)

**Symptoms:** I2C scanner runs but finds no devices

**Cause:**
- SDA/SCL shorted together
- Pull-up resistors missing
- ADS ICs not powered
- ADDR pins not properly connected

**Solutions:**
1. Check power:
   - U4 VCC should read 3.3V
   - U5 VCC should read 3.3V
2. Check I2C pull-ups:
   - Measure SDA when idle: should read 3.3V
   - Measure SCL when idle: should read 3.3V
   - If reading 0V: pull-ups may be shorted
3. Check ADDR pins:
   - U4 ADDR: should measure 0V (connected to GND)
   - U5 ADDR: should measure 3.3V (connected to 3V3)
4. Check solder on U4/U5:
   - Inspect SDA/SCL pins for cold solder
   - Reflow if necessary
5. Check for bridges on I2C lines

#### Problem: Random crashes or resets

**Symptoms:** ESP32 resets unexpectedly, behavior is inconsistent

**Cause:**
- Power supply inadequate
- Bad solder joint
- Decoupling capacitors missing
- Firmware bug

**Solutions:**
1. Check power supply:
   - Verify 5V input is stable (multimeter or oscilloscope)
   - Verify 3V3 output doesn't sag (should stay 3.2-3.4V)
   - Try different USB cable
   - Try powered USB hub instead of computer
2. Check decoupling caps:
   - Verify C5 (100nF) soldered near U3
   - Verify C6, C7 soldered near U4, U5
3. Check solder joints:
   - Visually inspect ESP32 module
   - Check all VCC/GND connections
   - Reflow if cold solder suspected
4. Check firmware:
   - Add watchdog timer
   - Add debug logging
   - Simplify code for testing

#### Problem: LED doesn't light up

**Symptoms:** No power indication LED visible

**Cause:**
- LED polarity reversed
- R7 (current limiting resistor) wrong value
- Cold solder on LED pads
- 3V3 rail not powered

**Solutions:**
1. Check 3V3 voltage: should read 3.3V
2. Check LED polarity:
   - Remove and inspect
   - Positive leg (long) should connect toward 3V3
   - Negative leg (short) should connect toward GND
3. Check R7: should be 1kΩ (not open circuit)
4. Reflow LED solder joints
5. Replace LED if still no luck

---

## Section 7: Post-Successful Assembly Checklist

Once board is working:

- [ ] Power LED illuminates
- [ ] USB recognized by computer (COM port visible)
- [ ] I2C devices detected (0x48 and 0x49)
- [ ] UART communication works (serial monitor at 115200 baud)
- [ ] All 6 ADC channels reading valid values
- [ ] Buttons (BOOT, RESET) function correctly
- [ ] BLE advertising works (visible on phone)
- [ ] Firmware flashes successfully via USB
- [ ] No unexplained resets or crashes
- [ ] Temperature stable (no hot spots)
- [ ] Board meets 50×70mm size requirement
- [ ] All connectors have proper pinout labels
- [ ] Documentation updated with lessons learned
- [ ] Enclosure/mounting solution designed
- [ ] Production-ready for next iterations

---

## Document Version

**Version:** 1.0
**Date:** March 2026
**For:** Rowing/Balance Board Rehabilitation Sensor PCB
**Manufacturing:** JLCPCB / PCBWay compatible

---

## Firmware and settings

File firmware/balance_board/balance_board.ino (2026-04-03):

/**
 * Balance Board — 4-Sensor FSR Bilateral Balance Monitor (ADS1115 version)
 * v3.0 — Added diagnostics, I2C retry, configurable PGA, serial commands
 *
 * Reads 4 square FSRs (Interlink 406 / Adafruit 1075) via two ADS1115 16-bit
 * ADC breakout boards over I2C. Each ADS handles one foot (2 sensors per board).
 *
 * Sensor layout (matches physical wiring):
 *   FL (front-left)  = left toe    → ADS @ 0x49 (RIGHT board), A1
 *   FR (front-right) = right toe   → ADS @ 0x48 (LEFT board), A0
 *   RL (rear-left)   = left heel   → ADS @ 0x49 (RIGHT board), A0
 *   RR (rear-right)  = right heel  → ADS @ 0x48 (LEFT board), A1
 *
 * Wiring (voltage divider):
 *   3.3V → R_pullup → junction → FSR → GND. ADS reads junction voltage.
 *   Target: R_pullup = 100kΩ for best dynamic range with body weight.
 *   Note: Some ADS1115 breakout boards have on-board pull-ups — check!
 *
 *   I2C: SDA = GPIO 4, SCL = GPIO 5
 *   ADS-LEFT  ADDR → GND  (address 0x48)
 *   ADS-RIGHT ADDR → 3.3V (address 0x49)
 *
 * Serial Commands (send via Serial Monitor):
 *   'd' — Diagnostic dump (raw voltages, estimated pull-up R)
 *   'r' — Recapture baseline (step off board first!)
 *   'g' — Cycle PGA gain (4.096 → 2.048 → 1.024 → 0.512 → 0.256 → 6.144 → 4.096)
 *   'h' — Print help / command list
 *
 * Hardware: ESP32-S3-DevKitC-1 N16R8 + 2x ADS1115 breakout boards
 */

#include <Wire.h>

// ─── Forward Declarations ─────────────────────────────────────────────────────
struct SensorMap;
struct SensorReading;
struct BalanceMetrics;
static BalanceMetrics compute_balance(SensorReading* s);
static void print_output(SensorReading* s, BalanceMetrics* m);
static void print_balance_bar(float left_pct);
static void run_diagnostic();
static void print_help();

// ─── I2C Configuration ────────────────────────────────────────────────────────
#define I2C_SDA     4
#define I2C_SCL     5
#define I2C_MAX_RETRIES  3    // Retry failed I2C reads

// ─── ADS1115 Addresses ────────────────────────────────────────────────────────
#define ADS_LEFT    0x48    // ADDR → GND
#define ADS_RIGHT   0x49    // ADDR → 3.3V

// ─── ADS1115 Register Map ─────────────────────────────────────────────────────
#define ADS_REG_CONVERSION  0x00
#define ADS_REG_CONFIG      0x01

// ─── ADS1115 Config Bits ──────────────────────────────────────────────────────
// [15]    OS: start single conversion = 1
// [14:12] MUX: single-ended input select
// [11:9]  PGA: gain (configurable at runtime)
// [8]     MODE: single-shot = 1
// [7:5]   DR: 128 SPS = 100
// [4:0]   Comparator: disabled = 11
#define ADS_MUX_A0       0x4000  // MUX[14:12] = 100 → AIN0 vs GND
#define ADS_MUX_A1       0x5000  // MUX[14:12] = 101 → AIN1 vs GND
#define ADS_MUX_A2       0x6000  // MUX[14:12] = 110 → AIN2 vs GND
#define ADS_MUX_A3       0x7000  // MUX[14:12] = 111 → AIN3 vs GND

static const uint16_t mux_channels[4] = { ADS_MUX_A0, ADS_MUX_A1, ADS_MUX_A2, ADS_MUX_A3 };

// ─── PGA Configuration ───────────────────────────────────────────────────────
// PGA bits [11:9] in config register
struct PGASetting {
    uint16_t bits;       // Config register bits for this gain
    float    fs_volts;   // Full-scale voltage
    float    lsb_mv;     // mV per count
    const char* label;
};

static const PGASetting pga_table[] = {
    { 0x0000, 6.144, 0.1875, "+/-6.144V" },  // index 0
    { 0x0200, 4.096, 0.125,  "+/-4.096V" },  // index 1 (default)
    { 0x0400, 2.048, 0.0625, "+/-2.048V" },  // index 2
    { 0x0600, 1.024, 0.03125,"+/-1.024V" },  // index 3
    { 0x0800, 0.512, 0.015625,"+/-0.512V"},  // index 4
    { 0x0A00, 0.256, 0.0078125,"+/-0.256V"}, // index 5
};
#define PGA_COUNT 6

static int pga_index = 3;  // Start at ±1.024V — best for body weight on FSRs
                            // Under 183lbs, junction voltage is ~49mV → 1560 counts
                            // (was ±6.144V before, giving only ~260 counts of range!)
                            // Baseline will clip at 32767 (3.3V >> 1.024V) — this is fine,
                            // it means all sensors have identical baseline = maximum resolution

// Build config base from current PGA (OS=1, single-shot, 128SPS, comp off)
// Bits: [15] OS=1, [14:12] MUX (set separately), [11:9] PGA (from table),
//       [8] MODE=1 (single-shot), [7:5] DR=100 (128SPS), [4:0] COMP=00011 (off)
static uint16_t get_config_base() {
    return 0x8103 | pga_table[pga_index].bits | 0x0080;
    // 0x8103 = OS(1) bit15 + MODE(1) bit8 + COMP_QUE(11) bits1:0
    // 0x0080 = DR[7:5] = 100 (128 SPS)
}

// ─── Sampling Configuration ───────────────────────────────────────────────────
#define OVERSAMPLE      4       // Average 4 ADS readings per sensor for noise rejection
#define OUTPUT_RATE_HZ  40      // Serial output rate (40Hz)
#define BAUD            115200

// ─── Baseline ─────────────────────────────────────────────────────────────────
#define BASELINE_SAMPLES    32
#define BASELINE_SETTLE_MS  1000
#define NOISE_THRESHOLD     50    // Lowered from 200 — detect smaller force differences

// ─── Sensor Mapping ───────────────────────────────────────────────────────────
// Index: 0=FL, 1=FR, 2=RL, 3=RR
struct SensorMap {
    uint8_t  ads_addr;
    uint16_t mux;
    const char* label;
};

static SensorMap sensor_map[4] = {
    { ADS_RIGHT, ADS_MUX_A1, "FL" },   // Front-left (left toe)  → ADS 0x49, A1
    { ADS_LEFT,  ADS_MUX_A0, "FR" },   // Front-right (right toe) → ADS 0x48, A0
    { ADS_RIGHT, ADS_MUX_A0, "RL" },   // Rear-left (left heel)  → ADS 0x49, A0
    { ADS_LEFT,  ADS_MUX_A1, "RR" },   // Rear-right (right heel) → ADS 0x48, A1
};

// ─── Global State ─────────────────────────────────────────────────────────────

struct SensorReading {
    int16_t  raw;       // Raw ADS1115 value (signed 16-bit)
    int16_t  zeroed;    // Baseline-subtracted
    float    force;     // Inverted so positive = more pressure
};

static int16_t baseline[4] = {0, 0, 0, 0};
static uint32_t last_output_ms = 0;
static const uint32_t output_interval_ms = 1000 / OUTPUT_RATE_HZ;
static uint32_t frame_count = 0;
static bool diagnostic_mode = false;    // When true, print raw+voltage every frame
static uint32_t i2c_errors = 0;        // Running count of I2C failures
static uint32_t i2c_retries_used = 0;  // Running count of retries that succeeded

// ─── ADS1115 I2C Functions (with retry) ─────────────────────────────────────

static void ads_write_config(uint8_t addr, uint16_t config) {
    Wire.beginTransmission(addr);
    Wire.write(ADS_REG_CONFIG);
    Wire.write((uint8_t)(config >> 8));
    Wire.write((uint8_t)(config & 0xFF));
    Wire.endTransmission();
}

static int16_t ads_read_conversion(uint8_t addr) {
    Wire.beginTransmission(addr);
    Wire.write(ADS_REG_CONVERSION);
    uint8_t err = Wire.endTransmission();
    if (err != 0) {
        i2c_errors++;
        return -1;  // Signal read failure
    }
    Wire.requestFrom(addr, (uint8_t)2);
    if (Wire.available() == 2) {
        uint8_t hi = Wire.read();
        uint8_t lo = Wire.read();
        return (int16_t)((hi << 8) | lo);
    }
    i2c_errors++;
    return -1;  // Signal read failure
}

static bool ads_conversion_ready(uint8_t addr) {
    Wire.beginTransmission(addr);
    Wire.write(ADS_REG_CONFIG);
    Wire.endTransmission();
    Wire.requestFrom(addr, (uint8_t)2);
    if (Wire.available() == 2) {
        uint8_t hi = Wire.read();
        Wire.read();
        return (hi & 0x80) != 0;
    }
    return false;
}

static int16_t ads_read_single(uint8_t addr, uint16_t mux_bits) {
    uint16_t config = get_config_base() | mux_bits;
    ads_write_config(addr, config);

    // Wait for conversion (128 SPS = ~8ms max)
    delayMicroseconds(8500);

    // Poll for completion
    int retries = 10;
    while (!ads_conversion_ready(addr) && retries-- > 0) {
        delayMicroseconds(500);
    }

    return ads_read_conversion(addr);
}

// Read with I2C retry — if we get -1 (failure), retry up to I2C_MAX_RETRIES times
static int16_t ads_read_reliable(uint8_t addr, uint16_t mux_bits) {
    for (int attempt = 0; attempt < I2C_MAX_RETRIES; attempt++) {
        int16_t val = ads_read_single(addr, mux_bits);
        if (val != -1) {
            if (attempt > 0) i2c_retries_used++;
            return val;
        }
        // Small delay before retry
        delayMicroseconds(1000);
    }
    // All retries failed — return 0 (will be caught as dropout)
    return 0;
}

static int16_t read_oversampled(uint8_t ads_addr, uint16_t mux_bits) {
    int32_t sum = 0;
    int good_reads = 0;
    for (int i = 0; i < OVERSAMPLE; i++) {
        int16_t val = ads_read_reliable(ads_addr, mux_bits);
        if (val != 0 || i == 0) {  // Accept 0 only on first read (could be legit)
            sum += val;
            good_reads++;
        }
    }
    if (good_reads == 0) return 0;
    return (int16_t)(sum / good_reads);
}

// ─── I2C Scanner (debug) ─────────────────────────────────────────────────────

static bool check_ads(uint8_t addr) {
    Wire.beginTransmission(addr);
    uint8_t err = Wire.endTransmission();
    return (err == 0);
}

// ─── Diagnostics ─────────────────────────────────────────────────────────────

static void run_diagnostic() {
    Serial.println();
    Serial.println("═══════════════════════════════════════════════════════");
    Serial.println("  DIAGNOSTIC DUMP");
    Serial.println("═══════════════════════════════════════════════════════");

    // Current PGA
    Serial.print("  PGA: ");
    Serial.print(pga_table[pga_index].label);
    Serial.print("  (LSB = ");
    Serial.print(pga_table[pga_index].lsb_mv, 4);
    Serial.println(" mV)");
    Serial.println();

    // Read raw values for all 4 channels on both boards
    Serial.println("  Board  Ch   Raw Count   Voltage(mV)  Voltage(V)");
    Serial.println("  -----  --   ---------   -----------  ----------");

    for (int i = 0; i < 4; i++) {
        int16_t raw = ads_read_reliable(sensor_map[i].ads_addr, sensor_map[i].mux);
        float mv = raw * pga_table[pga_index].lsb_mv;
        float v = mv / 1000.0;

        char buf[80];
        const char* board = (sensor_map[i].ads_addr == ADS_LEFT) ? "LEFT " : "RIGHT";
        const char* ch = (sensor_map[i].mux == ADS_MUX_A0) ? "A0" : "A1";
        snprintf(buf, sizeof(buf), "  %s  %s   %-10d  %-12.2f %-10.4f  [%s]",
                 board, ch, raw, mv, v, sensor_map[i].label);
        Serial.println(buf);
    }

    // Estimate pull-up resistor value
    // At no-load: junction ≈ 3.3V (R_fsr very high)
    // At load: V_junction = 3.3 × R_fsr / (R_pullup + R_fsr)
    // Baseline gives us unloaded voltage
    Serial.println();
    Serial.println("  Baseline values (captured at startup, unloaded):");
    for (int i = 0; i < 4; i++) {
        float base_mv = baseline[i] * pga_table[pga_index].lsb_mv;
        float base_v = base_mv / 1000.0;
        char buf[60];
        snprintf(buf, sizeof(buf), "    %s: %d counts = %.1f mV = %.3f V",
                 sensor_map[i].label, baseline[i], base_mv, base_v);
        Serial.println(buf);
    }

    // If we have a current reading, estimate R_pullup
    Serial.println();
    Serial.println("  Pull-up resistor estimate (if board is loaded):");
    Serial.println("  Assumes FSR ~ 5kΩ under body weight (~45 lbs/sensor)");
    for (int i = 0; i < 4; i++) {
        int16_t raw = ads_read_reliable(sensor_map[i].ads_addr, sensor_map[i].mux);
        float v_junction = raw * pga_table[pga_index].lsb_mv / 1000.0;
        // V = 3.3 × R_fsr / (R_pullup + R_fsr)
        // R_pullup = R_fsr × (3.3 / V - 1)
        if (v_junction > 0.01 && v_junction < 3.2) {
            float r_fsr_assumed = 5000.0;  // 5kΩ estimate
            float r_pullup_est = r_fsr_assumed * (3.3 / v_junction - 1.0);
            char buf[60];
            snprintf(buf, sizeof(buf), "    %s: V=%.3fV → R_pullup ≈ %.0f Ω (%.1f kΩ)",
                     sensor_map[i].label, v_junction, r_pullup_est, r_pullup_est / 1000.0);
            Serial.println(buf);
        } else {
            char buf[60];
            snprintf(buf, sizeof(buf), "    %s: V=%.3fV — cannot estimate (unloaded or clipped)",
                     sensor_map[i].label, v_junction);
            Serial.println(buf);
        }
    }

    // I2C health
    Serial.println();
    char errbuf[60];
    snprintf(errbuf, sizeof(errbuf), "  I2C errors: %lu  |  Retries used: %lu",
             (unsigned long)i2c_errors, (unsigned long)i2c_retries_used);
    Serial.println(errbuf);

    // Recommended PGA
    Serial.println();
    Serial.println("  PGA recommendation:");
    int16_t max_raw = 0;
    for (int i = 0; i < 4; i++) {
        int16_t raw = ads_read_reliable(sensor_map[i].ads_addr, sensor_map[i].mux);
        if (raw > max_raw) max_raw = raw;
    }
    float max_v = max_raw * pga_table[pga_index].lsb_mv / 1000.0;
    Serial.print("    Current max sensor voltage: ");
    Serial.print(max_v, 3);
    Serial.println(" V");

    // Find smallest PGA that still fits the max voltage (with 10% headroom)
    float needed = max_v * 1.1;
    for (int p = PGA_COUNT - 1; p >= 0; p--) {
        if (pga_table[p].fs_volts >= needed) {
            Serial.print("    Recommended PGA: ");
            Serial.print(pga_table[p].label);
            if (p == pga_index) {
                Serial.println(" (current — no change needed)");
            } else {
                Serial.println(" (press 'g' to cycle to this gain)");
            }
            break;
        }
    }

    Serial.println("═══════════════════════════════════════════════════════");
    Serial.println();
}

static void print_help() {
    Serial.println();
    Serial.println("──── Serial Commands ────");
    Serial.println("  'd' — Diagnostic dump (voltages, pull-up estimate, I2C health)");
    Serial.println("  'r' — Recapture baseline (step off board first!)");
    Serial.println("  'g' — Cycle PGA gain setting");
    Serial.println("  'v' — Toggle verbose mode (raw counts + voltage every frame)");
    Serial.println("  'h' — This help message");
    Serial.println("─────────────────────────");
    Serial.println();
}

// ─── Baseline Capture ─────────────────────────────────────────────────────────

static void capture_baseline() {
    Serial.println("Capturing baseline — keep the board UNLOADED...");
    delay(BASELINE_SETTLE_MS);

    int32_t accum[4] = {0, 0, 0, 0};
    for (int s = 0; s < BASELINE_SAMPLES; s++) {
        for (int i = 0; i < 4; i++) {
            accum[i] += read_oversampled(sensor_map[i].ads_addr, sensor_map[i].mux);
        }
        delay(5);
    }
    for (int i = 0; i < 4; i++) {
        baseline[i] = (int16_t)(accum[i] / BASELINE_SAMPLES);
    }

    Serial.print("Baseline captured: ");
    for (int i = 0; i < 4; i++) {
        float mv = baseline[i] * pga_table[pga_index].lsb_mv;
        char buf[40];
        snprintf(buf, sizeof(buf), "%s=%d (%.0fmV)", sensor_map[i].label, baseline[i], mv);
        Serial.print(buf);
        if (i < 3) Serial.print(", ");
    }
    Serial.println();

    // At low PGA gains (±1.024V or lower), baseline will clip at 32767
    // because unloaded junction voltage (~3.3V) exceeds the PGA range.
    // This is EXPECTED and actually desirable — all sensors get identical
    // baseline, maximizing resolution for the loaded voltage range.
    bool all_clipped = true;
    for (int i = 0; i < 4; i++) {
        if (baseline[i] < 32000) all_clipped = false;
        if (baseline[i] < 100) {
            Serial.print("  WARNING: ");
            Serial.print(sensor_map[i].label);
            Serial.println(" baseline very low — sensor may not be connected!");
        }
    }
    if (all_clipped && pga_index >= 2) {
        Serial.println("  (Baseline clipped at max — normal for this PGA gain)");
    }

    Serial.println("Ready — step on the board.  ('h' for commands)");
    Serial.println();
}

// ─── Force Estimation ─────────────────────────────────────────────────────────
// No pressure: R_fsr very high → junction ≈ 3.3V → ADS reads high
// Pressure: R_fsr drops → junction drops → ADS reads lower
// HIGHER pressure = LOWER ADS reading. We invert for intuitive output.

static float adc_to_force(int16_t zeroed_value) {
    float inverted = (float)(-zeroed_value);
    if (inverted < 0) inverted = 0;
    return inverted;
}

// ─── Balance Metrics ──────────────────────────────────────────────────────────

struct BalanceMetrics {
    float left_total;       // FL + RL
    float right_total;      // FR + RR
    float left_pct;
    float right_pct;
    float left_ap;          // +1 = ball, -1 = heel
    float right_ap;
    float front_pct;        // front sensors as % of total
    float total_force;
    bool  loaded;
};

static BalanceMetrics compute_balance(SensorReading* s) {
    BalanceMetrics m;

    m.left_total  = s[0].force + s[2].force;  // FL + RL
    m.right_total = s[1].force + s[3].force;  // FR + RR
    m.total_force = m.left_total + m.right_total;

    m.loaded = (m.total_force > NOISE_THRESHOLD * 2);

    if (m.total_force > 0.1) {
        m.left_pct  = 100.0 * m.left_total / m.total_force;
        m.right_pct = 100.0 * m.right_total / m.total_force;
        float front_total = s[0].force + s[1].force;  // FL + FR
        m.front_pct = 100.0 * front_total / m.total_force;
    } else {
        m.left_pct = 50.0;
        m.right_pct = 50.0;
        m.front_pct = 50.0;
    }

    if (m.left_total > 0.1) {
        m.left_ap = (s[0].force - s[2].force) / m.left_total;
    } else {
        m.left_ap = 0.0;
    }

    if (m.right_total > 0.1) {
        m.right_ap = (s[1].force - s[3].force) / m.right_total;
    } else {
        m.right_ap = 0.0;
    }

    return m;
}

// ─── Display ──────────────────────────────────────────────────────────────────

static void print_balance_bar(float left_pct) {
    int bar_width = 40;
    int marker = (int)(left_pct / 100.0 * bar_width);
    if (marker < 0) marker = 0;
    if (marker > bar_width) marker = bar_width;

    Serial.print("  L |");
    for (int i = 0; i < bar_width; i++) {
        if (i == bar_width / 2) Serial.print("|");
        else if (i == marker) Serial.print("*");
        else Serial.print("-");
    }
    Serial.println("| R");
}

static void print_output(SensorReading* s, BalanceMetrics* m) {
    if (frame_count % 40 == 0) {
        Serial.println();
        if (diagnostic_mode) {
            Serial.println("  FL      FR      RL      RR     | L%    R%   F%   | L-AP   R-AP | raw_FL  raw_FR  raw_RL  raw_RR");
            Serial.println("  ------  ------  ------  ------ | ----  ---- ---- | -----  ----- | ------  ------  ------  ------");
        } else {
            Serial.println("  FL      FR      RL      RR     | L%    R%   F%   | L-AP   R-AP");
            Serial.println("  ------  ------  ------  ------ | ----  ---- ---- | -----  -----");
        }
    }

    // Force values
    Serial.print("  ");
    for (int i = 0; i < 4; i++) {
        char buf[10];
        snprintf(buf, sizeof(buf), "%-8.0f", s[i].force);
        Serial.print(buf);
    }

    // Percentages (L/R and Front)
    Serial.print("| ");
    char pctbuf[32];
    snprintf(pctbuf, sizeof(pctbuf), "%-6.1f%-6.1f%-5.1f", m->left_pct, m->right_pct, m->front_pct);
    Serial.print(pctbuf);

    // A/P ratios
    Serial.print("| ");
    char apbuf[32];
    snprintf(apbuf, sizeof(apbuf), "%-7.2f%-7.2f", m->left_ap, m->right_ap);
    Serial.print(apbuf);

    // Verbose/diagnostic: also print raw ADC counts
    if (diagnostic_mode) {
        Serial.print("| ");
        for (int i = 0; i < 4; i++) {
            char buf[10];
            snprintf(buf, sizeof(buf), "%-8d", s[i].raw);
            Serial.print(buf);
        }
    }

    Serial.println();

    if (frame_count % 5 == 0 && m->loaded) {
        print_balance_bar(m->left_pct);
    }
}

// ─── Serial Command Handler ─────────────────────────────────────────────────

static void handle_serial_command(char cmd) {
    switch (cmd) {
        case 'd':
        case 'D':
            run_diagnostic();
            break;

        case 'r':
        case 'R':
            capture_baseline();
            break;

        case 'g':
        case 'G':
            pga_index = (pga_index + 1) % PGA_COUNT;
            Serial.print("PGA changed to: ");
            Serial.print(pga_table[pga_index].label);
            Serial.print("  (LSB = ");
            Serial.print(pga_table[pga_index].lsb_mv, 4);
            Serial.println(" mV)");
            Serial.println("NOTE: Baseline is now invalid — press 'r' to recapture!");
            break;

        case 'v':
        case 'V':
            diagnostic_mode = !diagnostic_mode;
            Serial.print("Verbose/diagnostic mode: ");
            Serial.println(diagnostic_mode ? "ON (showing raw counts)" : "OFF");
            break;

        case 'h':
        case 'H':
        case '?':
            print_help();
            break;

        default:
            break;  // Ignore unknown characters (newlines, etc.)
    }
}
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
void loop() {
    // Check for serial commands
    while (Serial.available()) {
        char c = Serial.read();
        handle_serial_command(c);
    }

    uint32_t now = millis();

    if ((now - last_output_ms) >= output_interval_ms) {
        last_output_ms = now;

        // Read all 4 sensors via ADS1115 (with retry)
        SensorReading readings[4];
        for (int i = 0; i < 4; i++) {
            readings[i].raw = read_oversampled(sensor_map[i].ads_addr, sensor_map[i].mux);
            readings[i].zeroed = readings[i].raw - baseline[i];
            readings[i].force = adc_to_force(readings[i].zeroed);
        }

        // Compute balance metrics
        BalanceMetrics metrics = compute_balance(readings);

        // Output
        if (metrics.loaded) {
            print_output(readings, &metrics);
        } else {
            if (frame_count % 20 == 0) {
                Serial.println("  (no load detected — step on the board)");
            }
        }

        frame_count++;
    }
}

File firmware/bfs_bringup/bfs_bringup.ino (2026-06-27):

/*
 * BFS Board Bring-Up Firmware — Rowing / Balance-Board Rehab Sensor PCB v2
 * -----------------------------------------------------------------------
 * Target: ESP32-S3-WROOM-1-N16R2  (custom "BFS" PCB, freelancer build)
 *
 * Hardware confirmed on the physical board via the I2C pin-finder (2026-05):
 *     I2C:  SDA = GPIO11, SCL = GPIO12
 *     ADS1115 @ 0x48   — 4 force channels A0..A3 (MCP6044 inverting front-end)
 *     BNO055  @ 0x28   — 9-DOF IMU, on-board 32.768 kHz crystal
 *
 * Channel map (per PCB_V2_REDESIGN_BRIEF, connectors J2..J5):
 *     A0 = Left Heel     A1 = Left Toe
 *     A2 = Right Heel    A3 = Right Toe
 *
 * FRONT-END POLARITY: FlexiForce drives an MCP6044 *inverting* amp, so Vout
 * RISES with applied force (~0 V no-load -> ~3 V full scale). Higher counts =
 * more force. This is the OPPOSITE of the old FSR voltage-divider prototype
 * (balance_board.ino), so do not reuse its inversion. With nothing plugged
 * into a channel, that channel just sits at its no-load baseline.
 *
 * OUTPUTS (both at once):
 *   - Serial @115200 : human-readable diagnostic (5 Hz) for bench bring-up
 *   - BLE "Rowing_Sensors" : 50 Hz notify, web-app-compatible payload —
 *       bytes 0..11  = 6x uint16 LE force (heel/ball/toe per foot; ball=0)
 *       bytes 12..17 = 3x int16 LE IMU Euler, centi-degrees (pitch/roll/yaw)
 *     The current web app reads only bytes 0..11 and ignores the IMU tail,
 *     so it keeps working; a future update can read orientation.
 *
 * BUILD (USB CDC on boot so Serial rides the S3 native USB — no UART bridge):
 *   arduino-cli compile/upload \
 *     -b esp32:esp32:esp32s3:USBMode=hwcdc,CDCOnBoot=cdc,FlashSize=16M \
 *     -p /dev/cu.usbmodem1101
 * READ SERIAL: tap RST1, then read /dev/cu.usbmodem* with RTS held low
 * (do NOT pulse reset from the host — that knocks the app over).
 */

#include <Wire.h>
#include <Adafruit_ADS1X15.h>
#include <Adafruit_Sensor.h>
#include <Adafruit_BNO055.h>
#include <utility/imumaths.h>
#include <BLEDevice.h>
#include <BLEServer.h>
#include <BLEUtils.h>
#include <BLE2902.h>

// ─── Confirmed pin map / addresses ───────────────────────────────────────────
#define I2C_SDA   11
#define I2C_SCL   12
#define ADS_ADDR  0x48
#define BNO_ADDR  0x28

// ─── Channel indices (J2..J5) ────────────────────────────────────────────────
enum { LEFT_HEEL = 0, LEFT_TOE = 1, RIGHT_HEEL = 2, RIGHT_TOE = 3 };
static const char* CH_LABEL[4] = { "L-Heel", "L-Toe ", "R-Heel", "R-Toe " };

// ─── BLE identity (must match web/src/hooks/useForceData.js) ──────────────────
#define BLE_NAME            "Rowing_Sensors"
#define SERVICE_UUID        "4fafc201-1fb5-459e-8bcc-c5c9c331914b"
#define CHARACTERISTIC_UUID "beb5483e-36e1-4688-b7f5-ea07361b26a8"

struct __attribute__((packed)) Payload {
  uint16_t left_heel;   // byte 0   (ADS A0)
  uint16_t left_ball;   // byte 2   always 0 — no ball sensor on this board
  uint16_t left_toe;    // byte 4   (ADS A1)
  uint16_t right_heel;  // byte 6   (ADS A2)
  uint16_t right_ball;  // byte 8   always 0
  uint16_t right_toe;   // byte 10  (ADS A3)
  int16_t  pitch_cd;    // byte 12  IMU pitch, centi-degrees
  int16_t  roll_cd;     // byte 14  IMU roll,  centi-degrees
  int16_t  yaw_cd;      // byte 16  IMU yaw/heading, centi-degrees
  uint8_t  cal;         // byte 18  BNO055 calibration: (sys<<6)|(gyro<<4)|(accel<<2)|mag, 0..3 each
};

// ─── Globals ──────────────────────────────────────────────────────────────────
Adafruit_ADS1115 ads;
Adafruit_BNO055  bno(55, BNO_ADDR, &Wire);

bool adsOK = false, bnoOK = false;

int16_t  gRaw[4]   = {0, 0, 0, 0};      // latest raw ADS counts (signed)
int16_t  gBase[4]  = {0, 0, 0, 0};      // per-channel no-load baseline (captured at boot)
float    gEuler[3] = {0, 0, 0};          // pitch, roll, yaw (deg)
uint8_t  gCal[4]   = {0, 0, 0, 0};       // sys, gyro, accel, mag (0..3)

BLEServer*         pServer = nullptr;
BLECharacteristic* pChar   = nullptr;
bool connected = false, wasConnected = false;

class SrvCB : public BLEServerCallbacks {
  void onConnect(BLEServer*)    override { connected = true;  Serial.println("[BLE] web app connected"); }
  void onDisconnect(BLEServer*) override { connected = false; Serial.println("[BLE] web app disconnected"); }
};

// ─── Helpers ──────────────────────────────────────────────────────────────────
static inline uint16_t clampU16(int v) { if (v < 0) return 0; if (v > 65535) return 65535; return (uint16_t)v; }

static void sampleSensors() {
  if (adsOK) {
    gRaw[LEFT_HEEL]  = ads.readADC_SingleEnded(0);
    gRaw[LEFT_TOE]   = ads.readADC_SingleEnded(1);
    gRaw[RIGHT_HEEL] = ads.readADC_SingleEnded(2);
    gRaw[RIGHT_TOE]  = ads.readADC_SingleEnded(3);
  }
  if (bnoOK) {
    imu::Vector<3> e = bno.getVector(Adafruit_BNO055::VECTOR_EULER);
    gEuler[0] = e.z();   // pitch
    gEuler[1] = e.y();   // roll
    gEuler[2] = e.x();   // yaw / heading
    bno.getCalibration(&gCal[0], &gCal[1], &gCal[2], &gCal[3]);
  }
}

static Payload buildPayload() {
  Payload p = {};
  p.left_heel  = clampU16(gRaw[LEFT_HEEL]  - gBase[LEFT_HEEL]);
  p.left_toe   = clampU16(gRaw[LEFT_TOE]   - gBase[LEFT_TOE]);
  p.right_heel = clampU16(gRaw[RIGHT_HEEL] - gBase[RIGHT_HEEL]);
  p.right_toe  = clampU16(gRaw[RIGHT_TOE]  - gBase[RIGHT_TOE]);
  // ball fields intentionally 0; force = raw - no-load baseline (rest -> 0)
  p.pitch_cd = (int16_t)(gEuler[0] * 100.0f);
  p.roll_cd  = (int16_t)(gEuler[1] * 100.0f);
  p.yaw_cd   = (int16_t)(gEuler[2] * 100.0f);
  p.cal      = (uint8_t)((gCal[0] << 6) | (gCal[1] << 4) | (gCal[2] << 2) | gCal[3]); // sys,gyro,accel,mag
  return p;
}

static void printDiag() {
  Serial.println("--------------------------------------------------------------");
  for (int i = 0; i < 4; i++) {
    int force = gRaw[i] - gBase[i]; if (force < 0) force = 0;
    Serial.printf("  %s  raw=%6d  base=%5d  force=%6d%s\n",
                  CH_LABEL[i], gRaw[i], gBase[i], force, adsOK ? "" : "  [ADS not found]");
  }
  if (bnoOK) {
    Serial.printf("  IMU   pitch=%7.2f  roll=%7.2f  yaw=%7.2f   cal[S%d G%d A%d M%d]\n",
                  gEuler[0], gEuler[1], gEuler[2], gCal[0], gCal[1], gCal[2], gCal[3]);
  } else {
    Serial.println("  IMU   [BNO055 not found @0x28]");
  }
  Serial.printf("  BLE   %s\n", connected ? "connected — streaming 50 Hz" : "advertising as \"" BLE_NAME "\"");
}
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

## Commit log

2026-04-03 Initial commit: consolidate rowing recovery sensor project
    Unified repo bringing together firmware (ESP32-S3 + dual ADS1115 + 6x FSR),
    React/Vite web app (BLE force monitoring), KiCad PCB design, and Python
    analysis tools from scattered development directories.
    [BOM.csv, Rowing-Sensor.kicad_pcb, Rowing-Sensor.kicad_sch]
2026-04-14 Add PCB V2 redesign brief: FlexiForce A301 sensor upgrade
    Replaces FSR-402 voltage dividers (100N max, frequent failures) with
    Tekscan FlexiForce A301 thin-film sensors (4,448N range, 0.2mm thick)
    and MCP6004 op-amp conditioning circuit. Eliminates V1 A0/A1 routing
    defect by consolidating to single ADS1115. Complete BOM, schematic,
    pinout, and calibration guide for freelancer PCB fabrication.
2026-04-14 Update sensor connectors to 2.54mm female headers
    FlexiForce A301 male pins plug directly into standard 2.54mm female
    through-hole headers — no adapter cables, instant sensor swap.
    Replaces JST-PH connectors throughout the brief.
2026-04-18 Redesign Balance Board view around Center of Pressure
    Makes CoP the dominant central element (460px) with live trajectory trail.
    Separate exercise views (Standing, Heel Rise, Squats) and three CoP training
    games (Target Tracking, Shape Tracing, Reactive Targets) based on
    evidence-based proprioceptive rehabilitation protocols.
    - useCoPMetrics hook: velocity, 95% confidence ellipse area, L/R symmetry
    with both rolling 10s window and full session window
    - CoPDisplay: large target with concentric rings, SVG trail, overlay slot
    for game-specific markers
    - StandingView: bilateral/single-leg modes with eyes-open/closed variants
    - HeelRiseView: forefoot load bar with 75% threshold, hold timer,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
2026-04-23 PCB V2 brief: add BNO055 IMU + dual-mode support + DOCX export
    Brief updated to v2.1 with:
    - BNO055 9-DOF IMU via breakout-module socket (shares I2C bus with ADS1115
    at address 0x28). Provides board tilt, trunk sway, and dynamic reference
    frame for CoP analysis.
    - BLE payload extended from 12 to 18 bytes (adds pitch/roll/yaw in 0.01°)
    - Dual-mode operation documented: same PCB for rowing (insole sensors) and
    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
2026-04-23 Rewrite PCB brief as fresh design document
    Removed V1-to-V2 diff framing throughout. Document now reads as a
    standalone design brief appropriate for a freelancer seeing the
    project for the first time. Also removed firmware reference section
    (not needed in a PCB brief — firmware is out of scope for the PCB
    designer).
2026-04-23 Integrate BNO055 directly on PCB (no breakout socket)
    Replaces the awkward breakout-module + socket approach with direct
    LGA-28 IC placement. JLCPCB PCBA handles the assembly — no
    post-delivery steps required. Adds 32.768 kHz crystal + 22pF load
    caps + decoupling directly to the BOM. Lower profile, more robust,
    cheaper per unit, and the board ships ready to flash.
2026-04-23 Address external review feedback on PCB brief
    - Upgrade LDO: AMS1117-3.3 → AP2112K-3.3 (55µA Iq vs 5mA,
    modern low-dropout, stable without large bulk cap)
    - Add ESD protection on all 4 sensor headers: 100Ω series
    resistor + PESD3V3L1BA TVS diode per input
    - Clean up op-amp topology explanation; reference Tekscan
    Integration Guide Figure 4 for exact polarity/biasing
    - Fix stale "off-board breakout via socket" reference in
    I²C address table; now correctly reads "LGA-28 on-board"
    - Clarify BOM intro: only off-board parts are FlexiForce sensors
2026-05-07 Standing view: vertical L/R bars under CoP for spatial alignment
    Replace stacked horizontal L/R weight bars with two side-by-side
    vertical fill bars. The left bar represents the left foot's weight
    share, right bar represents the right — mirroring the user's
    physical perception of standing on the board (left foot under left
    half of screen, right foot under right half).
    Each bar fills from bottom upward, has a 50% reference line, shows
    the percentage centered in the bar, and labels the foot below.
2026-06-27 Add balance & Achilles training modes, FlexiForce puck hardware, BFS bringup
    - New balance views: AnkleRocker, LeanTrainer, SideToSideLevel, CalibrationHelper
    - HeelRise/Standing refinements + useAchillesMetrics / useCoPMetrics hooks
    - firmware/bfs_bringup + i2c_pin_finder diagnostics
    - hardware/flexiforce_puck design
    [flexiforce_puck_4up_v2.step, flexiforce_puck_4up_v2.stl, flexiforce_puck_4up_v3.step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]
